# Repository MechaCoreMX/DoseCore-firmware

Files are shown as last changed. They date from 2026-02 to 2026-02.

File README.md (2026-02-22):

# DoseCore: Programmable Medication Dispenser

DoseCore is a programmable medication dispensing system designed to improve
medication adherence through scheduled alarms and controlled mechanical
compartment positioning.

This repository contains the complete research prototype, including:

- Embedded firmware (Arduino Mega 2560)
- Electrical schematics
- 3D-printable enclosure files (STL)
- Experimental validation dataset
- Statistical performance analysis notebook
- System architecture documentation

The project is currently under editorial review for publication in *HardwareX*.

---

# System Overview

DoseCore is a low-cost, microcontroller-based assistive device aimed at
supporting elderly users and patients with chronic conditions who require
scheduled medication intake.

The system integrates:

- Real-time clock (RTC-based scheduling)
- Servo-driven compartment positioning
- Reed switch feedback verification
- Keypad and LCD human–machine interface
- Audible alarm notification

The firmware ensures safe, repeatable, and verifiable dispensing actions.

---

## Hardware Platform

- **Microcontroller:** Arduino Mega 2560  
- **Actuator:** 360° continuous rotation servomotor (DS04-NFC)  
- **Positioning:** Neodymium magnet and reed switches  
- **User interface:** 4×4 matrix keypad, 16×2 LCD display  
- **Timing:** DS3231 Real-Time Clock (RTC)  
- **Audio feedback:** Buzzer  
- **Power:** External 12 V supply with DC–DC regulation  
- **Mechanical parts:** 3D-printed PLA components  

---

## Bill of Materials (BOM)

The following table lists the main components required to assemble the
**DoseCore: Programmable Medication Dispenser** prototype.  
All costs are indicative and provided for reference only.

| Component | Qty. | Unit cost (USD) | Total cost (USD) | Supplier | Material |
|---|---|---|---|---|---|
| Arduino Mega 2560 microcontroller | 1 | 24.50 | 24.50 | AliExpress | Microcontroller |
| 360° servomotor DS04-NFC | 1 | 2.72 | 2.72 | AliExpress | Electronic |
| LM2596 DC–DC regulator module | 1 | 1.02 | 1.02 | AliExpress | Electronic |
| DS3231 RTC module | 1 | 1.02 | 1.02 | AliExpress | Electronic |
| Passive buzzer | 1 | 0.10 | 0.10 | AliExpress | Electronic |
| Reed switch (Normally Open) | 4 | 0.102 | 0.408 | AliExpress | Electronic |
| 4×4 matrix keypad | 1 | 1.02 | 1.02 | AliExpress | Electronic |
| 16×2 LCD display (HD44780 compatible) | 1 | 1.02 | 1.02 | AliExpress | Electronic |
| Potentiometer 10 kΩ | 1 | 2.89 | 2.89 | AliExpress | Electronic |
| Resistor 220 Ω | 1 | 0.051| 0.051 | AliExpress | Electronic |
| Neodymium magnet (6 × 3 mm) | 1 | 0.102 | 0.102 | AliExpress | Electronic |
| AC/DC power supply 12 V – 3 A | 1 | 1.02 | 1.02 | AliExpress | Electronic |
| 3D-printed parts set (PLA) | ~150 g | 0.008 | 1.20 | AliExpress | Mechanical / Structural |
| 3Coil of 30 AWG copper wire (10 m) | 5 m | 0.102 | 0.51 | AliExpress | Conductor |

**Note:** Prices correspond to typical online suppliers and may vary depending on
region, availability, and purchase volume.

---

## Dependencies (Arduino Libraries)

The firmware was developed and tested using the **Arduino IDE** and requires the
following libraries to be installed before compilation.

### Required Libraries
Install the following libraries using the **Arduino Library Manager**
(`Sketch → Include Library → Manage Libraries`):

- **RTClib** (by Adafruit)  
  Used for communication with the DS3231 real-time clock module.

- **Keypad**  
  Provides support for scanning and decoding input from the 4×4 matrix keypad.

- **LiquidCrystal**  
  Handles the 16×2 LCD display (HD44780 compatible).  
  *(This library is included by default with the Arduino IDE.)*

- **Servo**  
  Used to control the continuous rotation servomotor.  
  *(This library is included by default with the Arduino IDE.)*

### Development Environment
- **Arduino IDE:** Version 2.x  
- **Target board:** Arduino Mega 2560  
- **Framework:** Arduino

### Notes
All third-party libraries can be installed directly from the Arduino Library
Manager. No additional external software dependencies are required to build
or run the firmware.

---

## Wiring / Pinout (Arduino Mega 2560)

This section provides a high-level overview of the electrical connections used in
the **DoseCore: Programmable Medication Dispenser** prototype.  
The authoritative and complete pin mapping is defined in the `pins.h` file.

### Actuators and Indicators
- **Servo motor (continuous rotation):** Digital pin **6**  
- **Buzzer:** Analog pin **A3** (configured as digital output)

### Positioning Sensors
All reed switches are configured as `INPUT_PULLUP` and are therefore
**active-low** (triggered when the signal is pulled to ground).

- **Home position reed switch:** Digital pin **7**  
- **Compartment A reed switch:** Digital pin **3**  
- **Compartment B reed switch:** Digital pin **4**  
- **Compartment C reed switch:** Digital pin **5**

### LCD Display (16×2, HD44780 compatible, parallel mode)
The LCD is connected in 4-bit parallel mode.

- **RS:** Digital pin **42**  
- **E:** Digital pin **44**  
- **D4:** Digital pin **46**  
- **D5:** Digital pin **48**  
- **D6:** Digital pin **50**  
- **D7:** Digital pin **52**

### Matrix Keypad (4×4)
- **Row pins:** Digital pins **22, 24, 26, 28**  
- **Column pins:** Digital pins **30, 32, 34, 36**

### Power
- **Logic supply:** 5 V provided by the Arduino Mega 2560  
- **External supply:** 12 V DC (used for the servo motor and power stage)

### Notes
- All pin assignments are centralized in `pins.h` to simplify hardware changes
  and improve reproducibility.
- Ground (GND) must be shared between the Arduino Mega 2560 and the external
  power supply.

---

# Repository Structure

```text
DoseCore/
│
├── main.ino
├── pins.h
├── config.h
├── types.h
├── globals.h
├── globals.cpp
├── motion.cpp / motion.h
├── ui.cpp / ui.h
├── alarm.cpp / alarm.h
│
├── hardware/
│   ├── schematics/
│   │   ├── diagrama.pdf
│   │   └── README.md
│   │
│   └── stl/
│       ├── Pillbox case body.STL
│       ├── Pillbox case low.STL
│       ├── Pillbox case top.STL
│       └── README.md
│
├── docs/
│   ├── DoseCore_system_architecture.pdf
│   ├── DoseCore_firmware_flowchart.pdf
│   └── README.md
│
├── data/
│   ├── raw/
│   │   ├── experimental_data.csv
│   │   └── README.md
│   │
│   ├── processed/
│   │   ├── summary_metrics.csv
│   │   └── README.md
│   │
│   └── README.md
│
├── analysis/
│   ├── performance_analysis.ipynb
│   └── README.md
│
├── legacy/
│   ├── Code-V1.ino
│   ├── Code-V2.ino
│   └── README.md
│
├── LICENSE
├── CITATION.cff
└── README.md
```

---

# Hardware Description

## Core Components

The DoseCore prototype is built around a modular embedded architecture
integrating mechanical, electronic, and control subsystems.

- **Microcontroller:** Arduino Mega 2560  
- **Actuator:** 360° continuous rotation servo motor (DS04-NFC)  
- **Position Feedback:** Reed switches (active-low configuration)  
- **User Interface:** 4×4 matrix keypad and 16×2 LCD (HD44780 compatible)  
- **Timing Module:** DS3231 Real-Time Clock (RTC)  
- **Power Supply:** 12 V external source with LM2596 DC–DC regulator  
- **Enclosure:** Custom 3D-printed PLA structure  

The complete electrical wiring diagram is provided in:

hardware/schematics/diagrama.pdf

3D printable enclosure components are available in:

hardware/stl/

---

# Firmware

The firmware is modular and organized into dedicated components for:

- Motion control
- Alarm management
- User interface handling
- Hardware abstraction

It is fully compatible with **Arduino IDE 2.x**.

### Required Libraries

Install using the Arduino Library Manager:

- RTClib (Adafruit)
- Keypad
- LiquidCrystal
- Servo

---

# Experimental Validation

The repository includes complete experimental validation data to ensure
scientific reproducibility.

## Raw Dataset

Located at:

data/raw/experimental_data.csv

The dataset includes 100 actuation cycles with measurements of:

- Angular positioning error (degrees)
- Idle current (mA)
- Peak current during actuation (mA)
- Success indicator (binary)

---

## Processed Metrics

Located at:

data/processed/summary_metrics.csv

The computed performance indicators include:

- Total cycles (n = 100)
- Success rate (100%)
- Mean angular error: 2.52°
- Standard deviation: 1.43°
- 95th percentile error: ~4.75°
- Maximum angular error: 5°
- Mean idle current: 90 mA
- Mean peak current: 479.2 mA

---

# Performance Analysis

The statistical analysis used to compute these metrics is available in:

analysis/performance_analysis.ipynb

Running the notebook reproduces all summary statistics reported in
`summary_metrics.csv`.

---

# Reproducibility

## Firmware

1. Clone or download the repository.
2. Install required Arduino libraries.
3. Open `main.ino` in Arduino IDE.
4. Select board: Arduino Mega 2560.
5. Compile and upload.

## Experimental Metrics

1. Ensure dataset is located in `data/raw/`.
2. Open `analysis/performance_analysis.ipynb`.
3. Run all cells sequentially.

The computed values should match those in
`data/processed/summary_metrics.csv`.

---

# Code Availability

The actively maintained firmware version is hosted on GitHub.

A stable release corresponding to the manuscript is archived on Zenodo
and assigned a DOI to ensure long-term preservation and citation.

Citation metadata is provided in the `CITATION.cff` file.

---

# License

This software is released under the **Apache License 2.0**.

The license permits academic and commercial use, modification, and
redistribution, provided that proper attribution is maintained.

See the `LICENSE` file for the complete license text.

---

# Intellectual Property Notice

This firmware is associated with a hardware system for which a patent
application is currently under evaluation.

The open-source distribution of this software does **not** grant rights
to manufacture, commercialize, or reproduce the associated hardware
design without authorization from the authors.

This repository is intended for scientific transparency, academic
dissemination, and reproducibility of the research prototype.

---

# Legacy Code

The `legacy/` directory contains earlier monolithic firmware versions
used during initial prototyping.

These files are provided for historical reference only and are not
required to compile or operate the current firmware version.

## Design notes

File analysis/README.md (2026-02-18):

# Performance Analysis Notebook

This directory contains the computational analysis used to evaluate the
mechanical accuracy and electrical performance of the
**DoseCore: Programmable Medication Dispenser**.

The analysis reproduces all statistical metrics reported in the associated
HardwareX manuscript.

---

## Included File

### `performance_analysis.ipynb`

Jupyter Notebook used to:

- Load the raw experimental dataset
- Compute angular positioning statistics
- Calculate success rate
- Estimate mean and standard deviation of currents
- Determine the 95th percentile (P95) angular error
- Generate processed performance metrics

The notebook processes the dataset located in:

data/raw/experimental_data.csv

and produces the summary metrics stored in:

data/processed/summary_metrics.csv

---

## Computed Metrics

The notebook calculates:

### Mechanical Performance
- Total number of cycles (`n_cycles`)
- Success rate
- Mean angular error
- Standard deviation of angular error (σ)
- 95th percentile angular error (P95)
- Maximum angular error

### Electrical Performance
- Mean idle current
- Standard deviation of idle current
- Mean peak current
- Standard deviation of peak current

---

## Requirements

The notebook was developed using:

- Python 3.x
- NumPy
- Pandas
- Matplotlib (if plots are generated)

Recommended installation:

```bash
pip install numpy pandas matplotlib

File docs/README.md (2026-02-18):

# System Architecture and Functional Documentation

This directory contains high-level architectural and functional diagrams
of the **DoseCore: Programmable Medication Dispenser** system.

These documents describe both the global system structure and the detailed
firmware control logic implemented in the device.

---

## Included Files

### 1. `DoseCore_system_architecture.pdf`

This document presents the high-level system architecture, including:

- Overall system workflow
- Interaction between hardware and firmware modules
- Alarm scheduling and execution overview
- User interaction sequence
- Mechanical dispensing process

This diagram provides a conceptual understanding of how the system operates
as an integrated hardware–software platform.

---

### 2. `DoseCore_firmware_flowchart.pdf`

This document contains the detailed firmware control flow, including:

- System initialization procedure
- RTC configuration and validation
- Alarm comparison logic
- Buzzer activation
- Servo actuation control
- Reed switch feedback verification
- Compartment positioning sequence
- Return-to-home logic

This diagram reflects the logic implemented in the firmware source files:

main.ino
alarm.cpp
motion.cpp
ui.cpp

---

## Purpose

These documents support the reproducibility of the firmware behavior and
complement the following repository sections:

- Electrical schematics (`hardware/schematics/`)
- 3D printable parts (`hardware/stl/`)
- Experimental dataset (`data/`)
- Source firmware implementation (root directory)

---

## Notes

The diagrams represent the research prototype configuration described in the
associated HardwareX manuscript. Minor implementation details may vary in
future firmware revisions.

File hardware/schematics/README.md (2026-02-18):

# Electrical Schematic

This directory contains the electrical connection diagram of the
**DoseCore: Programmable Medication Dispenser** prototype.

The schematic illustrates the complete wiring configuration between the
Arduino Mega 2560 and all peripheral components used in the system.

---

## Included File

### `DoseCore_electrical_diagram.pdf`

Electrical connection diagram of the full system, including:

- (H) Arduino Mega 2560 (ATmega2560)
- (J) DS3231 Real-Time Clock (RTC)
- (C) 4×4 matrix keypad
- (E) 16×2 LCD display (HD44780 compatible, 1602A)
- (D) 360° continuous rotation servo motor
- (I) LM2596 DC–DC voltage regulator
- (F) Reed switches (compartment positioning sensors)
- (K) Buzzer
- (L) Potentiometer (LCD contrast control)
- (N) External 12 V power supply

---

## System Architecture Overview

The system is centered around the Arduino Mega 2560 microcontroller,
which manages:

- Time-based scheduling via the DS3231 RTC (I2C interface: SDA/SCL)
- User input through the 4×4 matrix keypad
- Visual feedback using the 16×2 LCD (4-bit parallel mode)
- Mechanical actuation through a 360° servo motor
- Compartment position detection using reed switches
- Audible alerts via buzzer

The servo motor is powered through an LM2596 DC–DC regulator supplied
by an external 12 V source.

---

## Power Distribution

- Logic supply: 5 V from Arduino Mega 2560
- External supply: 12 V DC input
- Servo powered via regulated DC–DC module (LM2596)
- All grounds (GND) are common and shared

Proper grounding between the Arduino and external power stage is
required to ensure stable operation.

---

## Interface Details

### I2C Communication
- DS3231 connected via SDA and SCL lines

### LCD (16×2, 4-bit mode)
- RS, E, D4–D7 connected to digital pins
- Potentiometer used to adjust display contrast

### Keypad
- 4 row lines and 4 column lines connected to digital pins

### Reed Switches
- Configured as digital inputs (active-low with internal pull-up)

### Servo
- Controlled through a PWM-capable digital pin

---

## Reproducibility

This schematic reflects the exact wiring configuration used to collect
the experimental data reported in the associated manuscript.

The firmware in the root directory of this repository corresponds
directly to the pin mapping represented in this schematic.

---

## Notes

- Minor adjustments may be required depending on hardware revisions.
- Always verify voltage levels before powering the system.
- The schematic represents the research prototype configuration.

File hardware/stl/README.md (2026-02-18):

# 3D Printable Parts (STL Files)

This directory contains the 3D printable components required to assemble the
external enclosure of the **DoseCore: Programmable Medication Dispenser**.

All files are provided in STL format and are intended for FDM-based 3D printing.

---

## Included Files

### 1. `Pillbox case body.STL`
Main structural body of the device.  
This component houses the internal electronic system and supports the
mechanical dispensing mechanism.

### 2. `Pillbox case low.STL`
Lower enclosure component.  
Provides structural stability and interfaces with the main body section.

### 3. `Pillbox case top.STL`
Upper cover component.  
Designed to enclose and protect the internal compartments and electronics.

---

## Printing Recommendations

- Recommended material: PLA  
- Layer height: 0.2 mm  
- Infill: 20–30%  
- Nozzle diameter: 0.4 mm  
- Supports: Required depending on printer orientation  
- Bed adhesion: Brim recommended  

Total material usage for the enclosure is approximately 150 g of PLA.

---

## Assembly Notes

- Components are designed to fit together using standard FDM tolerances.
- Minor post-processing (light sanding) may improve fit depending on printer calibration.
- Ensure dimensional calibration of the printer before fabrication.

---

## Intellectual Property Notice

These STL files correspond to the enclosure components associated with the
DoseCore system. The publication of these files supports reproducibility of
the research prototype.

The associated hardware system is subject to a patent application currently
under evaluation. Redistribution and use of these files must comply with the
licensing and intellectual property terms described in the main repository.

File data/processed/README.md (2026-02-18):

# Processed Performance Metrics

This directory contains the statistical performance indicators derived from the
raw experimental dataset used to validate the operation of the
**DoseCore: Programmable Medication Dispenser**.

The metrics summarize the angular positioning accuracy and electrical
performance of the device across 100 actuation cycles.

---

## File Description

### `summary_metrics.csv`

This file contains aggregated statistical metrics computed from the raw dataset
located in:

data/raw/experimental_data.csv

Each row includes:

- `metric` — Name of the performance indicator  
- `value` — Computed numerical result  
- `unit` — Measurement unit (degrees, mA, percent, cycles)  
- `description` — Brief explanation of the metric  

---

## Reported Metrics

### Mechanical Performance

- **n_cycles** — Total number of actuation cycles evaluated (100 cycles)  
- **success_rate** — Percentage of successful compartment alignments (100%)  
- **mean_angular_error** — Average angular positioning error (2.52°)  
- **std_angular_error (σ)** — Standard deviation of angular positioning error (1.43°)  
- **p95_angular_error** — 95th percentile of angular positioning error (~4.75°)  
- **max_angular_error** — Maximum observed angular error (5°)  

### Electrical Performance

- **mean_idle_current** — Average current consumption at rest (90 mA)  
- **std_idle_current (σ)** — Standard deviation of idle current (0 mA)  
- **mean_peak_current** — Average peak current during actuation (479.2 mA)  
- **std_peak_current (σ)** — Standard deviation of peak current during actuation (14.54 mA)  

---

## Reproducibility

All metrics in this directory are computed using the analysis notebook:

analysis/performance_analysis.ipynb

Executing the notebook with the provided raw dataset will reproduce the
statistical results contained in `summary_metrics.csv`.

---

## Notes

These processed metrics correspond to the quantitative validation results
reported in the associated HardwareX manuscript and are provided to ensure
full scientific transparency, reproducibility, and long-term archival through
the Zenodo release associated with this repository.

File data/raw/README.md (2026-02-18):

# Raw Experimental Data

This directory contains the raw experimental measurements collected during the
validation of the **DoseCore: Programmable Medication Dispenser**.

The dataset includes mechanical positioning error and electrical consumption
measurements recorded across multiple actuation cycles.

---

## File Description

### `experimental_data.csv`

This file contains raw measurements obtained from 100 independent actuation
cycles of the device.

Each row corresponds to a single cycle and includes the following variables:

- `cycle` — Sequential cycle identifier  
- `angular_error` — Absolute angular positioning error (degrees)  
- `idle_current` — Current consumption in rest condition (mA)  
- `peak_current` — Maximum current recorded during actuation (mA)  
- `success` — Binary indicator of successful compartment alignment (1 = success, 0 = failure)  

---

## Experimental Conditions

- Total cycles evaluated: 100  
- Actuation performed under controlled laboratory conditions  
- Angular error measured relative to the expected compartment alignment position  
- Electrical measurements acquired during steady rest and peak actuation phases  

---

## Usage

This dataset serves as the basis for computing the statistical performance
metrics located in:

data/processed/summary_metrics.csv

All summary statistics reported in the associated manuscript are derived from
this raw dataset using the analysis notebook:

analysis/performance_analysis.ipynb

---

## Notes

The data provided in this directory represent unprocessed measurements and
are included to ensure full reproducibility and scientific transparency.

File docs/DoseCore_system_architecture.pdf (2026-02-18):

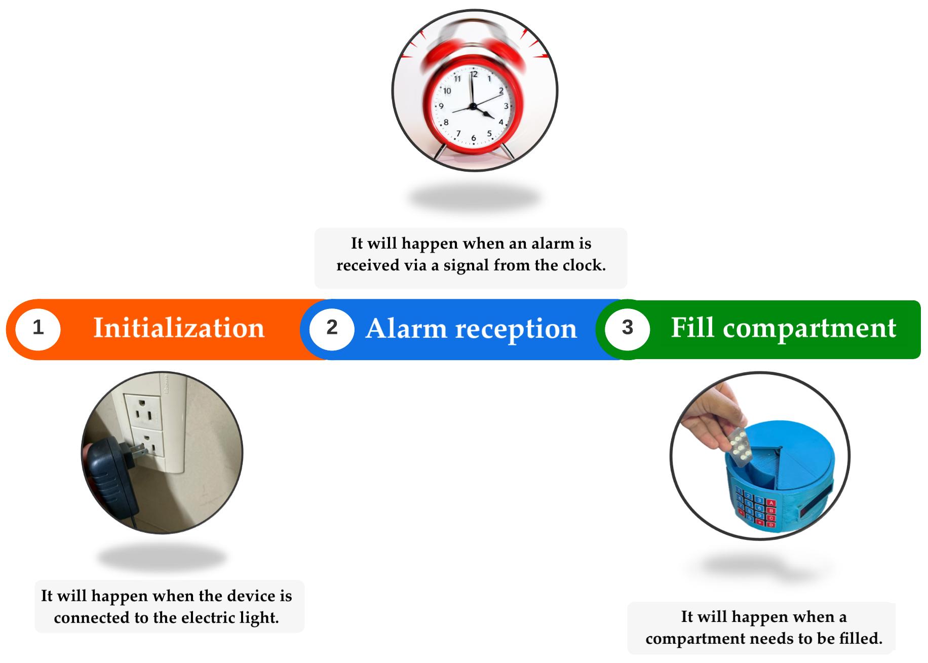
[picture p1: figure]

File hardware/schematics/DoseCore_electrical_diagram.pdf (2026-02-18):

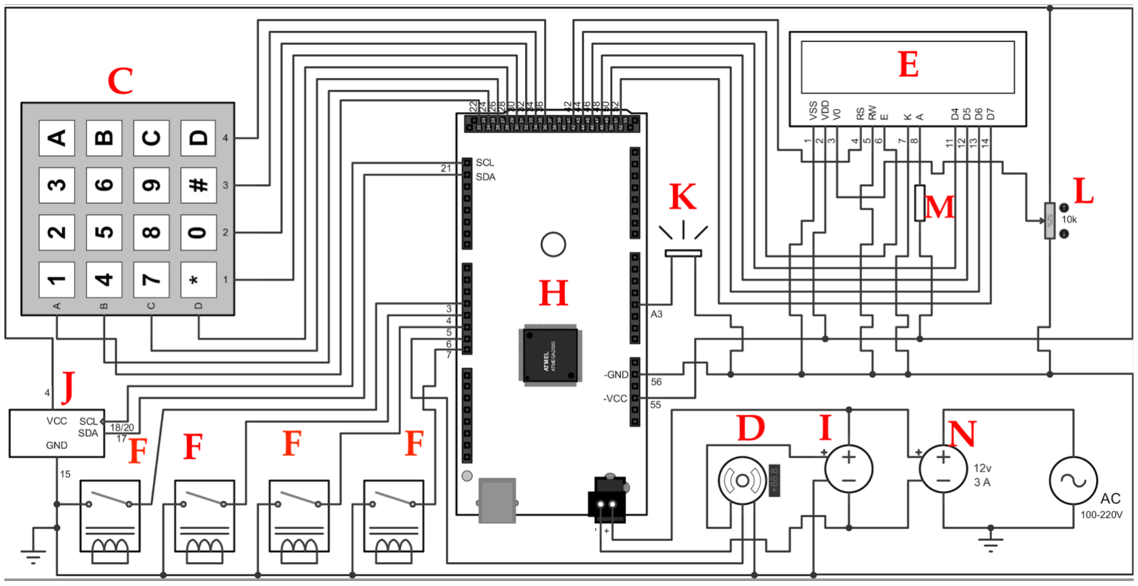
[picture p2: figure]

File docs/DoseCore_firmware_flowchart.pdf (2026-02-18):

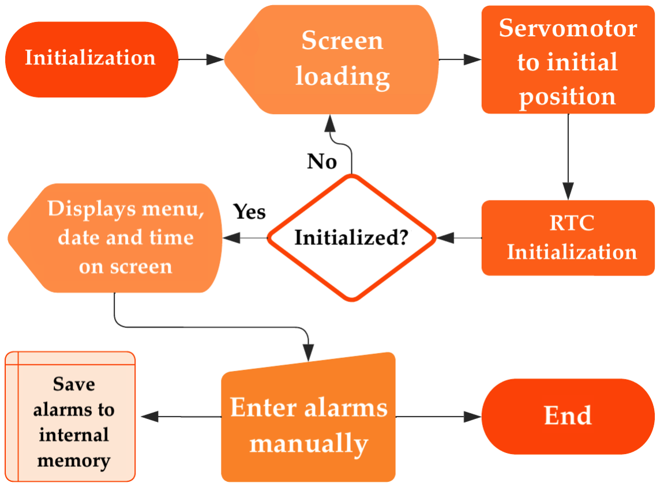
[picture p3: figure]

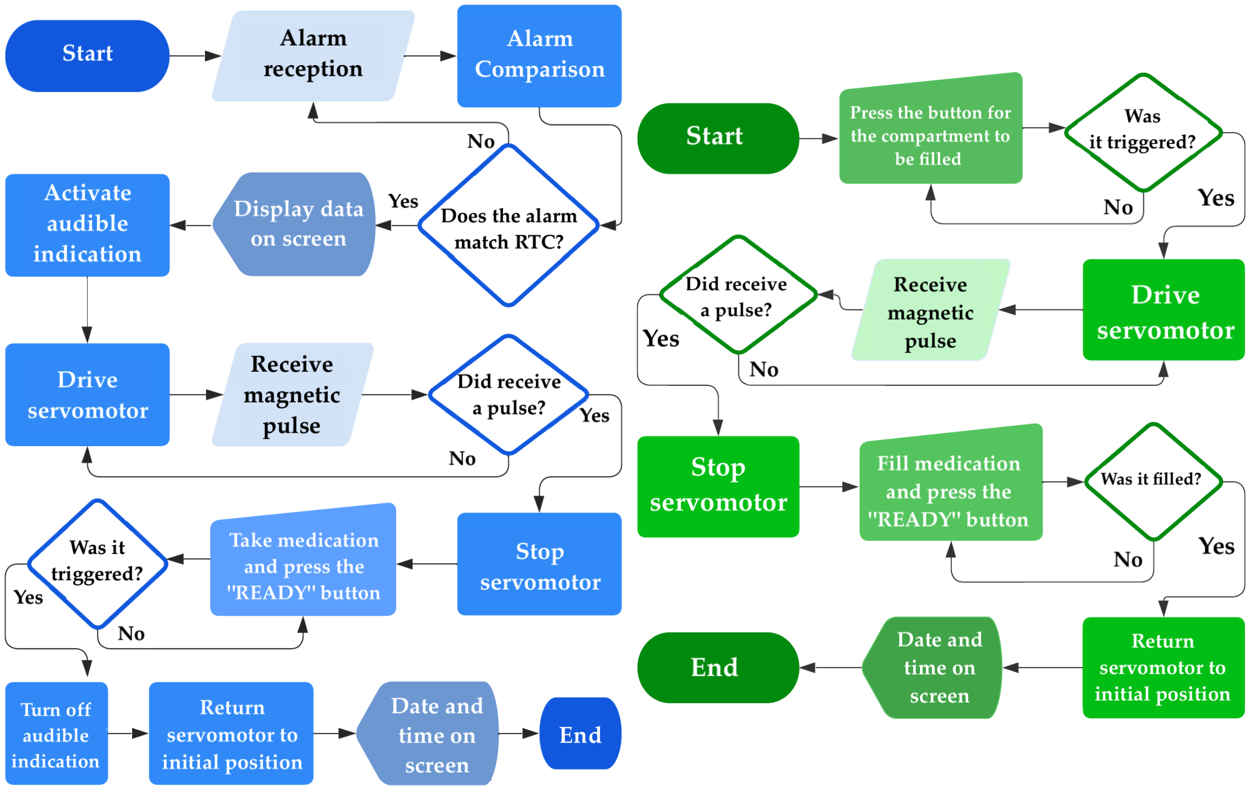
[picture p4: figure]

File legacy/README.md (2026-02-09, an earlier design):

# Legacy Firmware

This directory contains earlier monolithic firmware versions used during the
initial prototyping phase of the DoseCore system.

These files are provided for historical reference only and are **not** required
to compile or run the current firmware version.

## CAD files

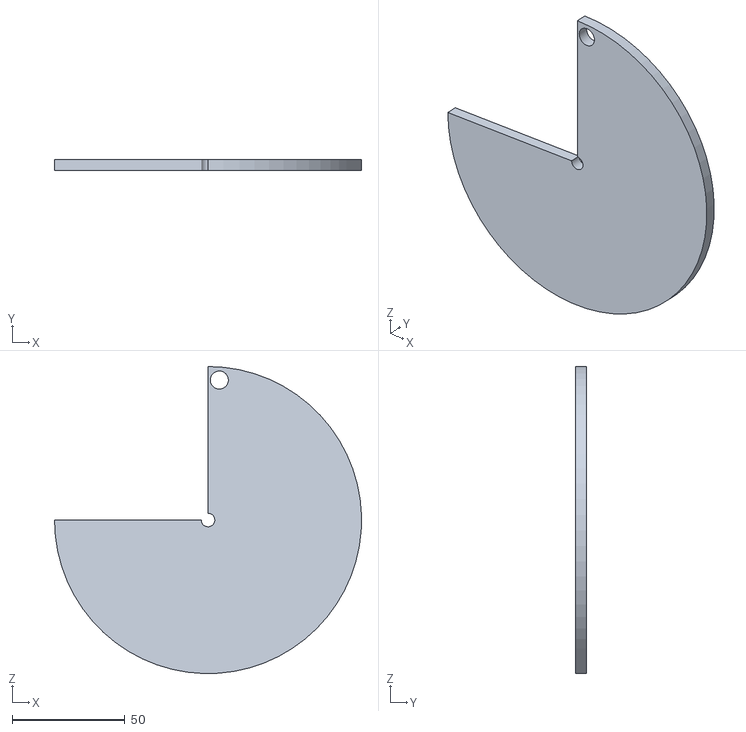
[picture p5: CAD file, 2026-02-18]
hardware/stl/Pillbox case top.STL
136.0 x 5.00 x 136.0

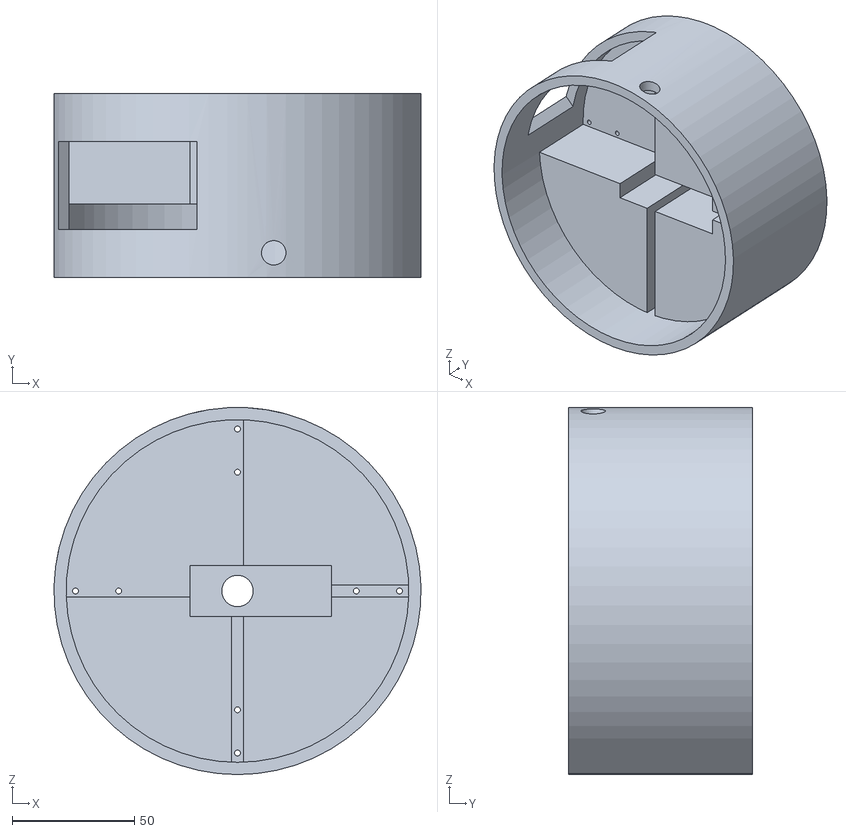
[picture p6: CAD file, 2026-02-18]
hardware/stl/Pillbox case body.STL
149.9 x 75.0 x 150.0

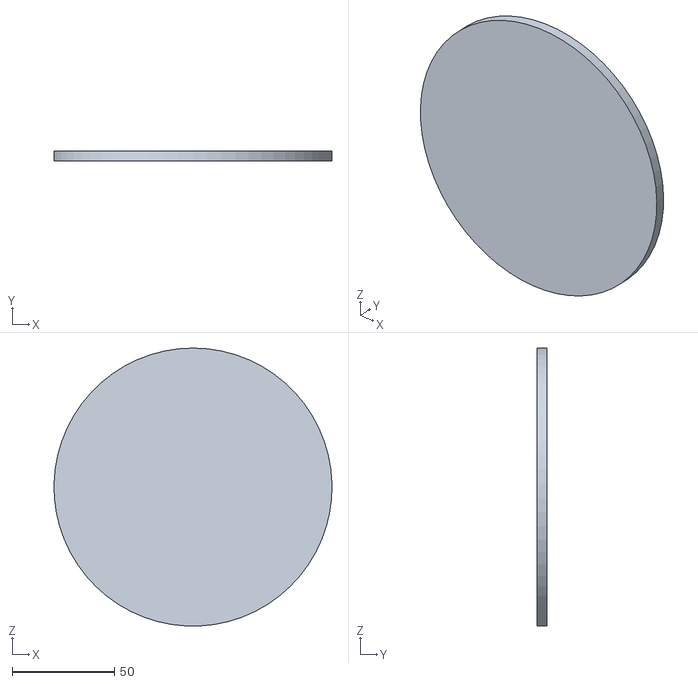
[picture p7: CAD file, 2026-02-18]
hardware/stl/Pillbox case low.STL
136.0 x 5.00 x 135.9

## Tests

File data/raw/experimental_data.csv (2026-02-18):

cycle | HOME | target_compartment | target_angle_deg | measured_angle_deg | error_deg | success_1_0 | I_idle_mA | I_peak_mA
1 | 0 | A | 90 | 92 | 2 | 1 | 90 | 460
2 | 3 | A | 90 | 94 | 4 | 1 | 90 | 470
3 | 4 | A | 90 | 92 | 2 | 1 | 90 | 490
4 | 4 | A | 90 | 91 | 1 | 1 | 90 | 490
5 | 2 | A | 90 | 90 | 0 | 1 | 90 | 480
6 | 3 | A | 90 | 94 | 4 | 1 | 90 | 460
7 | 2 | A | 90 | 92 | 2 | 1 | 90 | 480
8 | 2 | A | 90 | 94 | 4 | 1 | 90 | 470
9 | 1 | A | 90 | 91 | 1 | 1 | 90 | 490
10 | 1 | A | 90 | 92 | 2 | 1 | 90 | 460
11 | 3 | A | 90 | 90 | 0 | 1 | 90 | 490
12 | 4 | A | 90 | 94 | 4 | 1 | 90 | 460
13 | 3 | A | 90 | 92 | 2 | 1 | 90 | 480
14 | 3 | A | 90 | 91 | 1 | 1 | 90 | 470
15 | 4 | A | 90 | 94 | 4 | 1 | 90 | 490
16 | 1 | A | 90 | 90 | 0 | 1 | 90 | 460
17 | 3 | A | 90 | 92 | 2 | 1 | 90 | 480
18 | 4 | A | 90 | 94 | 4 | 1 | 90 | 470
19 | 1 | A | 90 | 91 | 1 | 1 | 90 | 490
20 | 2 | A | 90 | 92 | 2 | 1 | 90 | 460
21 | 3 | A | 90 | 90 | 0 | 1 | 90 | 480
22 | 0 | A | 90 | 94 | 4 | 1 | 90 | 470
23 | 4 | A | 90 | 92 | 2 | 1 | 90 | 490
24 | 3 | A | 90 | 91 | 1 | 1 | 90 | 460
25 | 1 | A | 90 | 94 | 4 | 1 | 90 | 480
26 | 2 | A | 90 | 90 | 0 | 1 | 90 | 470
27 | 4 | A | 90 | 92 | 2 | 1 | 90 | 490
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

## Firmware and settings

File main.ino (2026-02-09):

#include <Wire.h>
#include "pins.h"
#include "config.h"
#include "globals.h"
#include "motion.h"
#include "ui.h"
#include "alarm.h"

void setup(){
  Wire.begin();

  lcd.begin(LCD_COLS, LCD_ROWS);
  lcd.clear();
  lcd.print("Pastillero V2");
  delay(800);
  lcd.clear();

  if (!rtc.begin()){
    lcd.print("RTC FAIL");
    while(1);
  }
  // rtc.adjust(DateTime(__DATE__, __TIME__)); // solo 1 vez si lo necesitas

  pinMode(PIN_BUZZER, OUTPUT);

  pinMode(PIN_REED_HOME, INPUT_PULLUP);
  pinMode(PIN_REED_A,    INPUT_PULLUP);
  pinMode(PIN_REED_B,    INPUT_PULLUP);
  pinMode(PIN_REED_C,    INPUT_PULLUP);

  servito.attach(PIN_SERVO);
  servito.write(SERVO_STOP);

  // Inicializa horarios deshabilitados
  for (int c=0;c<4;c++){
    for (int d=0;d<3;d++){
      scheduleTbl[c][d].hour = 0;
      scheduleTbl[c][d].minute = 0;
      scheduleTbl[c][d].enabled = false;
    }
  }

  // Homing automático
  lcd.print("Buscando HOME.");
  bool okHome = moveUntilReed(HOME, SERVO_CCW, HOME_TIMEOUT_MS);
  lcd.clear();
  lcd.print(okHome ? "HOME OK" : "HOME FAIL");
  delay(800);
  lcd.clear();
}

void loop(){
  DateTime now = rtc.now();
  showDateTime(now);

  // Teclas: A/B/C manual, D configurar 1 dosis
  char k = teclado.getKey();
  if (k == 'A')      manualOpen(A);
  else if (k == 'B') manualOpen(B);
  else if (k == 'C') manualOpen(C);
  else if (k == 'D') configOneDose();

  // Revisar alarmas (anti re-disparo)
  int ms = minuteStamp(now);

  for (uint8_t comp = A; comp <= C; comp++){
    for (uint8_t d=0; d<3; d++){
      if (!scheduleTbl[comp][d].enabled) continue;

      if (now.hour() == scheduleTbl[comp][d].hour &&
          now.minute() == scheduleTbl[comp][d].minute){

        int key = comp*10 + d;
        if (!(lastTriggeredMinuteStamp == ms && lastTriggeredKey == key)){
          lastTriggeredMinuteStamp = ms;
          lastTriggeredKey = key;
          runAlarm((Comp)comp, d);
        }
      }
    }
  }

  delay(LOOP_DELAY_MS);
}

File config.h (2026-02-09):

#include <Arduino.h>

// Servo commands (rotación continua)
static const uint8_t SERVO_STOP = 90;
static const uint8_t SERVO_CW   = 99;
static const uint8_t SERVO_CCW  = 72;

// Tecla ACK (silenciar / regresar HOME)
static const char KEY_ACK = '6';

// Timing / seguridad
static const uint16_t REED_DEBOUNCE_MS    = 25;
static const uint16_t LOOP_DELAY_MS       = 150;
static const uint32_t MOVE_TIMEOUT_MS     = 6000;
static const uint32_t HOME_TIMEOUT_MS     = 7000;

// LCD
static const uint8_t LCD_COLS = 16;
static const uint8_t LCD_ROWS = 2;

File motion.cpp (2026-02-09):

#include "globals.h"
#include "config.h"
#include "motion.h"

bool reedStableLOW(uint8_t pin, uint16_t debounce_ms){
  if (digitalRead(pin) != LOW) return false;
  delay(debounce_ms);
  return (digitalRead(pin) == LOW);
}

bool moveUntilReed(Comp target, uint8_t servoCmd, unsigned long timeout_ms){
  unsigned long t0 = millis();
  servito.write(servoCmd);

  while (millis() - t0 < timeout_ms){
    if (reedStableLOW(compCfg[target].reedPin, REED_DEBOUNCE_MS)){
      servito.write(SERVO_STOP);
      return true;
    }
  }
  servito.write(SERVO_STOP);
  return false;
}

bool moveToComp(Comp target, unsigned long timeout_ms){
  return moveUntilReed(target, compCfg[target].cmdTo, timeout_ms);
}

bool returnHomeFrom(Comp from, unsigned long timeout_ms){
  return moveUntilReed(HOME, compCfg[from].cmdBack, timeout_ms);
}

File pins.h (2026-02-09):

#include <Arduino.h>

// Servo / Buzzer
static const uint8_t PIN_SERVO  = 6;
static const uint8_t PIN_BUZZER = A3;

// Reeds (INPUT_PULLUP => activo LOW)
static const uint8_t PIN_REED_HOME = 7;
static const uint8_t PIN_REED_A    = 3;
static const uint8_t PIN_REED_B    = 4;
static const uint8_t PIN_REED_C    = 5;

// LCD 16x2 paralelo (LiquidCrystal)
static const uint8_t PIN_LCD_RS = 42;
static const uint8_t PIN_LCD_E  = 44;
static const uint8_t PIN_LCD_D4 = 46;
static const uint8_t PIN_LCD_D5 = 48;
static const uint8_t PIN_LCD_D6 = 50;
static const uint8_t PIN_LCD_D7 = 52;

// Keypad 4x4
static const uint8_t KEYPAD_ROWS = 4;
static const uint8_t KEYPAD_COLS = 4;

static const uint8_t PIN_KEYPAD_ROWS[KEYPAD_ROWS] = {22,24,26,28};
static const uint8_t PIN_KEYPAD_COLS[KEYPAD_COLS] = {30,32,34,36};

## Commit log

2026-02-09 Create pins.h
    Role: Hardware pin mapping.
    Description:
    Defines all microcontroller pin assignments for the Arduino Mega 2560, including the servo motor, buzzer, reed switches, LCD display, and matrix keypad.
    Purpose:
    Separates physical wiring configuration from system logic, enabling hardware changes without modifying functional code.
    [pins.h]
2026-02-09 Create main.ino
    Role: Firmware entry point.
    Initializes all hardware components (RTC, LCD, servo motor, buzzer, reed switches) and executes the initial homing procedure of the mechanical system.
    The setup() function performs system configuration, while the loop() function implements the high-level execution flow, including time monitoring, user input handling, and alarm triggering.
    Provides a clear and readable overview of the global firmware logic without embedding low-level implementation details.
    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
    [main.ino]
2026-02-09 Create config.h
    Role: Global system configuration.
    Contains global constants and configurable parameters such as servo control commands, debounce times, movement timeouts, loop delays, and special control keys.
    Centralizes system calibration and timing parameters, facilitating tuning, testing, and future system updates.
    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
2026-02-20 Update README.md
    Correction in bill of materials
